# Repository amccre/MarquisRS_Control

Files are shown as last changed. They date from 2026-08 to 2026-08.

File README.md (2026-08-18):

# Marquis Recreational Series Hot Tub Control

ESPHome firmware, a custom display-decoder component, Home Assistant configuration, circuit documentation, and fabrication files for controlling and monitoring a Marquis Recreational Series hot tub with an ESP32.

> [!CAUTION]
> A spa combines lethal **120/240 V AC**, high-current equipment, water, and wet-location wiring. This is an experimental hobby project, not a listed or certified spa controller. Retain all factory safety controls and GFCI protection. Use appropriate isolation, fusing, grounding, strain relief, moisture protection, and enclosures. Disconnect and verify power before opening equipment. Installation should be completed or reviewed by a qualified electrician. You assume all risk.

<p align="center">
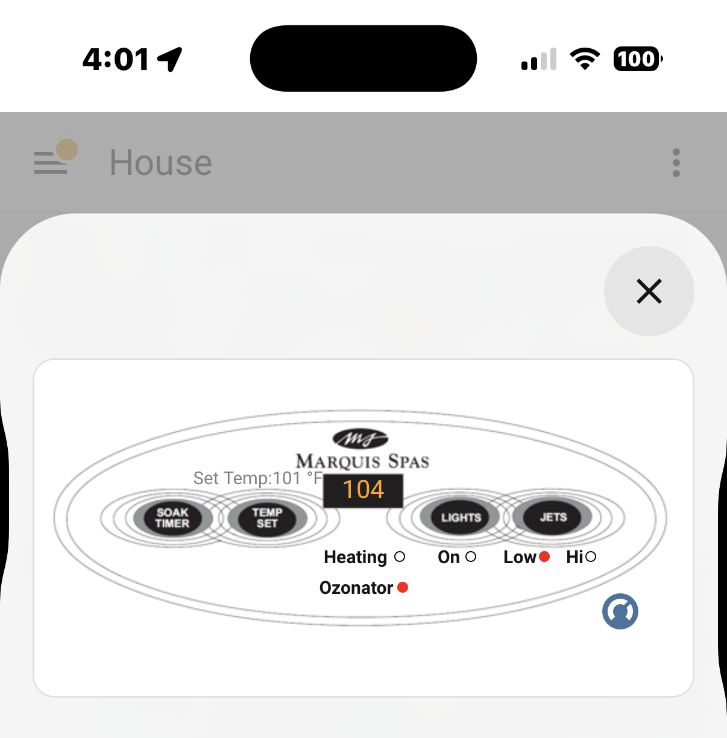
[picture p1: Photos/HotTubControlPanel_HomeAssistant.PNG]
Home Assistant hot tub control panel
  
</p>

## Overview

The project was developed for circa-2000-and-newer Marquis Recreational Series models such as the **Quest RS**, **Destiny RS**, and **Reward RS**. It preserves the original topside panel while adding network visibility and control:

- passively samples the panel clock and data lines;
- decodes the three-character, seven-segment LCD data and heater indicator;
- exposes **Soak Timer**, **Temp Set**, **Lights**, and **Jets** as Home Assistant buttons;
- monitors lights, ozonator, low-speed jets, and high-speed jets with split-core current transformers;
- creates a Home Assistant climate entity and target-temperature workflow; and
- provides example automations and a popup dashboard modeled after the original panel.

This implementation is hardware-specific. Marquis changed hardware over time, so verify connector pinout, logic levels, signal behavior, and button circuitry on your own equipment before connecting it.

## Repository Contents

```text
.
├── ESPHomeComponents/
│   └── marquis_rs_interface_component/
│       ├── hot-tub-control.yaml          # ESP32/ESPHome device configuration
│       ├── secrets.example.yaml          # Safe local-secret template
│       ├── README.md                     # Display protocol/component details
│       └── my_components/
│           └── marquis_rs_interface/     # Custom ESPHome component
├── HomeAssistantComponents/
│   ├── Automation-*.yaml                 # Four supporting automations
│   ├── script.hot_tub_*.txt              # Temperature-adjustment script
│   ├── DashboardExampleConfig.txt        # Example Lovelace view
│   ├── Helpers_Required.txt               # Required helper entities
│   ├── HACs_Components_Required.txt       # Third-party UI/integration list
│   └── files/
│       ├── configuration.yaml            # Climate/template configuration
│       └── www/                           # Dashboard image assets
├── Photos/                                # Build and finished-install images
├── ReverseEngineering/                    # Protocol captures and pinout research
├── CircuitDiagram.png                     # Browser-friendly circuit diagram
├── Circuit_Diagram.pdf                    # Printable circuit diagram
├── Circuit_Diagram.odg                    # Editable circuit source
├── Enclosure-Blank.stl                    # Blank enclosure model
├── HotTubControlEnclosure.stl             # Finished enclosure model
└── Buttons&CTs.txt                         # Original controls and CT notes
```

## Hardware

### Principal Components

| Quantity | Component | Purpose |
| ---: | --- | --- |
| 1 | ESP32 development board (`esp32dev`) | ESPHome controller and display decoder |
| 1 | ADS1115 at I²C address `0x48` | Four-channel CT input ADC |
| 2 | SCT-013-005, 5 A : 1 V | Lights and ozonator monitoring |
| 2 | SCT-013-010, 10 A : 1 V | Low- and high-speed jet monitoring |
| As required | Optocouplers/transistor stages | Isolated simulation of panel buttons |
| 1 | External USB power supply | Dedicated power for the ESP32/ESP8266 |
| As required | Fuse, connectors, enclosure | Safe permanent installation |

See the [PDF drawing](Circuit_Diagram.pdf), [editable ODG source](Circuit_Diagram.odg), and [original component notes](Buttons%26CTs.txt) before assembly.

<p align="center">
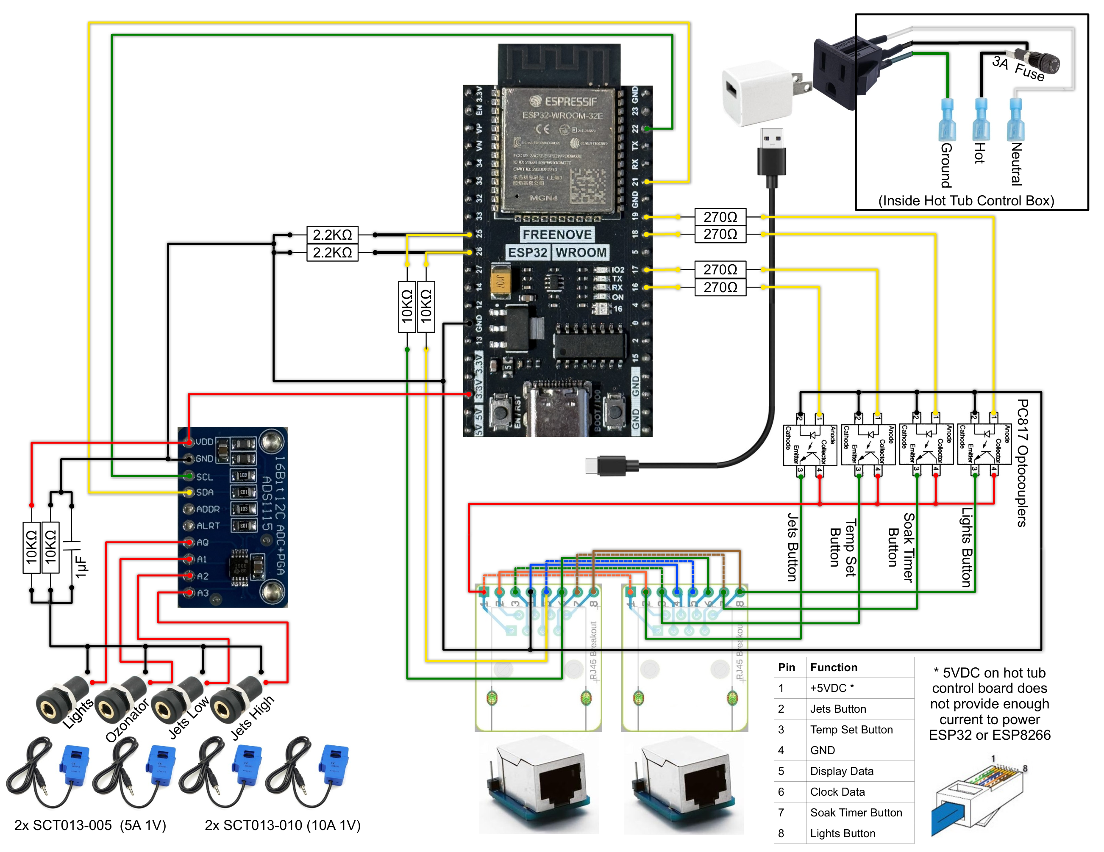
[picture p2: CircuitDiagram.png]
Marquis Recreational Series ESP32 interface circuit diagram
  
</p>

### Microcontroller Power

> [!IMPORTANT]
> The 5 V DC supplied by the hot tub control board does not provide enough current to power an ESP32 or ESP8266. The hot tub controller will reboot continuously if you try to use it to power the microcontroller. This made it necessary to use an external USB power supply.

Use a suitably rated, safety-certified USB supply and preserve the signal reference/isolation arrangement shown in the circuit diagram. Do not increase the load on the spa's 5 V rail in an attempt to eliminate the external supply. Keep the low-voltage USB supply and wiring protected from water, condensation, mains terminals, pumps, and heater conductors.

### ESP32 Pin Assignments

| Pin | Function |
| --- | --- |
| GPIO25 | Topside-display clock input |
| GPIO26 | Topside-display data input |
| GPIO19 | Lights button output |
| GPIO18 | Soak Timer button output |
| GPIO17 | Temp Set button output |
| GPIO16 | Jets button output |
| GPIO21 | ADS1115 SDA |
| GPIO22 | ADS1115 SCL |

Button outputs pulse for 150 ms. ESP32 pins must drive the documented interface circuitry; do **not** connect a GPIO directly to mains or an unverified panel circuit.

### Topside RJ45 Pinout

The reverse-engineering worksheet identifies the eight topside-connector conductors as follows. Confirm orientation and voltage on your own controller before relying on this table.

| RJ45 pin | Signal |
| ---: | --- |
| 1 | +5 V DC |
| 2 | Jets button |
| 3 | Temp Set button |
| 4 | Ground |
| 5 | Display data |
| 6 | Display clock |
| 7 | Soak Timer button |
| 8 | Light button |

### Current Monitoring

| ADS1115 channel | Load | Initial on-threshold | Calibration in supplied YAML |
| --- | --- | ---: | ---: |
| A0 | Lights | 0.75 A | 1 raw → 5 A |
| A1 | Ozonator | 0.05 A | 1 raw → 5 A |
| A2 | Jets low | 2 A | 1 raw → 10 A |
| A3 | Jets high | 2 A | 1 raw → 10 A |

These values describe one installation. Place each CT around **one conductor only**, compare readings with a trusted meter/known load, and tune both `calibrate_linear` and binary-sensor thresholds.

### Completed Installation

The finished interface is mounted in its printed enclosure near the spa equipment while preserving separation between the low-voltage electronics and high-voltage equipment wiring.

<table>
  <tr>
    <td align="center" width="50%">
      Completed Marquis hot tub controller installation, first view<br>
      <sub>Mounted controller and surrounding equipment</sub>
    </td>
    <td align="center" width="50%">
      Completed Marquis hot tub controller installation, second view<br>
      <sub>Installed enclosure and wiring, alternate view</sub>
    </td>
  </tr>
</table>

## ESPHome Installation

### 1. Copy the Project

Clone this repository on the host running ESPHome, then enter the component directory:

```bash
git clone https://github.com/amccre/MarquisRS_Control.git
cd MarquisRS_Control/ESPHomeComponents/marquis_rs_interface_component
```

### 2. Create Local Secrets

Copy `secrets.example.yaml` to `secrets.yaml` and replace every placeholder. The resulting file is ignored by Git.

```powershell
Copy-Item secrets.example.yaml secrets.yaml
```

Or on Linux/macOS:

```bash
cp secrets.example.yaml secrets.yaml
```

Required values are `wifi_ssid`, `wifi_password`, `api_encryption_key`, `ota_password`, and `fallback_ap_password`.

Generate a compatible API encryption key with `openssl rand -base64 32`, or let ESPHome generate one. Use unique random values for OTA and fallback access. Credentials formerly present in the local source were deliberately replaced with secret references and should be rotated if still in use.

### 3. Review and Flash

Before applying power, verify board type, GPIO assignments, ADS1115 address, logic levels, electrical isolation, CT channels, calibration, and thresholds.

```bash
esphome config hot-tub-control.yaml
esphome run hot-tub-control.yaml
```

Use USB for the initial flash. Once connected, later updates can use ESPHome OTA.

### 4. Add the Device to Home Assistant

In Home Assistant, open **Settings → Devices & services** and add the discovered ESPHome device. Supply the API encryption key from your local `secrets.yaml` when requested.

Expected entities include:

- `sensor.hot_tub_display` (the entity may initially include the ESPHome device prefix);
- `binary_sensor.hot_tub_control_heating`;
- lights, ozonator, jets-low, and jets-high binary sensors/current sensors; and
- four button entities for Soak Timer, Temp Set, Lights, and Jets.

Entity IDs in the supplied Home Assistant examples assume the names shown above. If Home Assistant generates different IDs, update the examples before enabling them.

## Home Assistant Configuration

The files in [`HomeAssistantComponents`](HomeAssistantComponents/) are examples to merge into an existing Home Assistant installation—not a drop-in replacement for your complete configuration.

### 1. Install Optional Custom Components

The supplied UI/configuration uses the following projects:

- [HACS](https://github.com/hacs/integration), to manage custom integrations;
- [Template Climate](https://github.com/jcwillox/hass-template-climate), required for `climate.hot_tub_thermostat`;
- [Bubble Card](https://github.com/Clooos/Bubble-Card), used for the popup panel;
- [card-mod](https://github.com/thomasloven/lovelace-card-mod), potentially needed for styling; and
- a `custom:text-action-element` card used by the example dashboard (install a compatible text-action element or replace those elements with built-in labels).

Restart Home Assistant after installing custom integrations/frontend resources.

### 2. Create Helpers

Create these helpers under **Settings → Devices & services → Helpers**:

| Entity ID | Type | Minimum | Maximum | Suggested icon |
| --- | --- | ---: | ---: | --- |
| `input_number.hot_tub_target_temperature` | Number | 80 | 104 | `mdi:target` |
| `input_number.hot_tub_set_temperature` | Number | 80 | 104 | `mdi:hot-tub` |
| `input_number.hot_tub_temperature` | Number | 0 | 120 | `mdi:hot-tub` |
| `input_boolean.hot_tub_ignore_sync` | Toggle | — | — | `mdi:pause` |

Use a step of `1` and °F as the unit for the number helpers. Template sensors are created in the next step.

### 3. Merge the Climate and Template Configuration

Merge [`HomeAssistantComponents/files/configuration.yaml`](HomeAssistantComponents/files/configuration.yaml) into your Home Assistant `configuration.yaml`. Do **not** overwrite an existing file wholesale. If you already have `climate:` or `template:` sections, merge entries while preserving valid YAML structure.

The configuration creates `climate.hot_tub_thermostat`, `sensor.hot_tub_temperature`, `sensor.hot_tub_set_temperature`, and `sensor.hot_tub_error_code`.

Run **Developer Tools → YAML → Check configuration**, then restart Home Assistant.

### 4. Add the Script and Automations

Import or recreate the supplied script first:

- [`script.hot_tub_read_adjust_to_target.txt`](HomeAssistantComponents/script.hot_tub_read_adjust_to_target.txt) reads the displayed setpoint and repeatedly presses Temp Set until the requested target is reached.

Then add the four automations:

1. [`Automation-Capture_Blinking_Set-Temp.yaml`](HomeAssistantComponents/Automation-Capture_Blinking_Set-Temp.yaml) captures the blinking setpoint display.
2. [`Automation-Record_LCD_temperature_when_stable.yaml`](HomeAssistantComponents/Automation-Record_LCD_temperature_when_stable.yaml) records stable water-temperature readings.
3. [`Automation-Sync_Set-Temp→Target.yaml`](HomeAssistantComponents/Automation-Sync_Set-Temp%E2%86%92Target.yaml) synchronizes a manually observed setpoint to the target helper.
4. [`Automation-Apply_New_Target_Temp.yaml`](HomeAssistantComponents/Automation-Apply_New_Target_Temp.yaml) invokes the adjustment script after the target changes.

Review every entity ID before enabling these automations. The adjustment script physically issues button presses and assumes the panel wraps through its setpoint range; test it while observing the real panel.

### 5. Install Dashboard Assets and Example

Copy the contents of [`HomeAssistantComponents/files/www`](HomeAssistantComponents/files/www/) to Home Assistant's `/config/www/`. Files there are exposed as `/local/...` URLs after a restart/browser refresh.

Use [`DashboardExampleConfig.txt`](HomeAssistantComponents/DashboardExampleConfig.txt) as a starting point for a raw Lovelace dashboard. It contains installation-specific floor-plan positioning and an `/api/image/serve/...` reference; replace that background with your own image URL or upload the desired panel image to `/config/www/` and use `/local/<filename>`.

## How Display Decoding Works

The custom [`marquis_rs_interface`](ESPHomeComponents/marquis_rs_interface_component/my_components/marquis_rs_interface/) component samples the panel data line on display-clock edges and reconstructs 21-bit frames, sent most-significant bit first.

<p align="center">
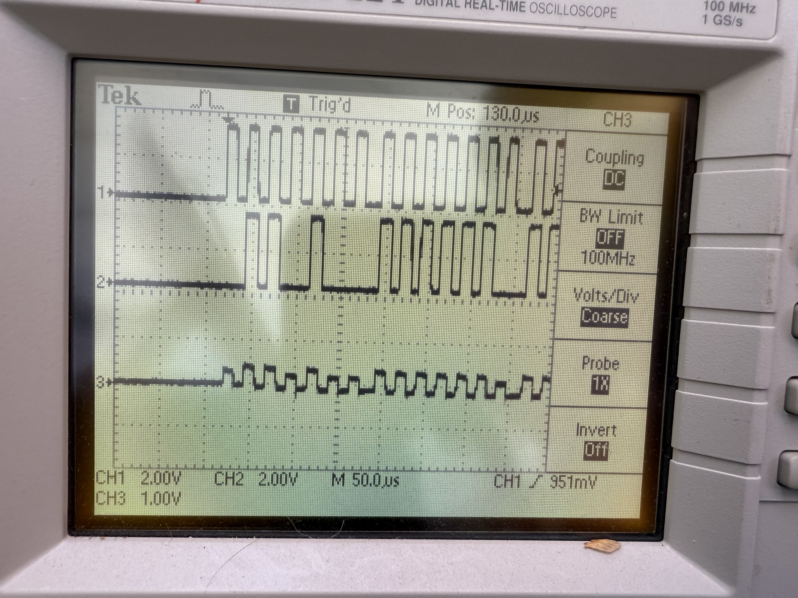
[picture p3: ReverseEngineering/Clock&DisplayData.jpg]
Oscilloscope capture of the Marquis topside display clock and data signals
  
</p>

### Display Data and Clock Timing

Measurements from the captured installation show:

- data starts **1 µs before** the clock pulse;
- data ends **1 µs after** the clock pulse;
- each data pulse is **12 µs** wide;
- gaps between pulses are **12 µs**;
- gaps between display segments are **19 µs**;
- gaps between complete sequences are approximately **17 ms**; and
- button-control pulses are **150 ms**.

The firmware interrupt is triggered by a rising clock edge and waits approximately **16 µs** before reading the data line. After **21 clocked bits**, the completed frame is queued for decoding. The implementation also treats a gap over **1,000 µs (1 ms)** as a frame boundary; the measured 17 ms inter-sequence gap comfortably exceeds that threshold. These values were measured on this installation and are not a manufacturer-guaranteed protocol specification, so remeasure if another controller revision behaves differently.

```text
Bit:      20 | 19 18 | 17 | 16 | 15 14 | 13 ........ 7 | 6 ......... 0
Meaning:   - | first |  - |heat|   -   | middle digit | final digit
```

- Bits 19–18 indicate a leading `1` or blank.
- Bit 16 is the heater indicator.
- Bits 13–7 and 6–0 hold seven-segment character patterns.
- Three consecutive identical frames are required to reject noise; stable state publication is rate-limited to 100 ms.
- A 16-frame ring buffer transfers captures from the interrupt handler to ESPHome's main loop.

### Seven-Segment Character Decoding

The final 14 frame bits represent two seven-segment characters. Each seven-bit value maps segments `A` through `G`, ordered from most-significant to least-significant bit:

```text
       A
      ---
   F |   | B
      -G-
   E |   | C
      ---
       D

Bit order: A B C D E F G
```

For example, `1111110` lights segments A–F and leaves G off, producing `0`; `0110000` lights B and C, producing `1`; and `1101101` produces `2`. The component contains a lookup table for digits `0`–`9`, a useful subset of letters shown by spa status/error codes, blank (`0000000`), and `?` for an unknown pattern. A leading `1` is encoded separately in frame bits 19–18, allowing the three-character display to represent values such as `102` as well as two-digit temperatures.

See the [component documentation](ESPHomeComponents/marquis_rs_interface_component/README.md) and [`ReverseEngineering`](ReverseEngineering/) folder for protocol details and captures.

An example [`ESPHomeLogs.png`](Photos/ESPHomeLogs.png) screenshot is included with the build photos as a reference for the decoded output seen during operation.

## Troubleshooting

### Display is blank, unstable, or shows `???`

- Verify connector pinout and signal voltage with appropriate test equipment.
- Confirm clock, data, and reference connections.
- Use high-impedance taps and appropriate level shifting/buffering.
- Keep low-voltage signal wiring away from motors, relays, and heater wiring.
- Enable debug logging while diagnosing frame capture.

### Current-based state is always on or off

- Inspect the underlying current sensor value.
- Confirm the CT surrounds one conductor, not both line and return.
- Verify ADS1115 channel assignments and CT type.
- Calibrate with a known load, then adjust state thresholds.

### A control button does not work

- Verify the isolation/driver circuit, polarity, and selected panel switch.
- Confirm a 150 ms closure is suitable for the physical panel.
- Never attach a bare GPIO to an unknown-voltage circuit.

### Climate target does not track correctly

- Confirm the display entity contains a numeric value during normal operation.
- Confirm all helper and ESPHome entity IDs match the example YAML.
- Ensure the four automations and adjustment script are enabled.
- Observe the panel while testing to validate blink timing and setpoint wraparound.

## Security

- `secrets.yaml`, ESPHome build state, IDE metadata, and Python caches are ignored.
- The checked-in ESPHome YAML references secrets rather than storing credentials.
- Rotate credentials that were ever embedded in another copy of this project.
- Repository visibility is not a substitute for secret management.

## License

This project is licensed under the [GNU General Public License v3.0 or later](LICENSE) (`GPL-3.0-or-later`). You may use, study, modify, and redistribute the project; if you distribute a modified version, the GPL requires the corresponding source and the same license freedoms to remain available. Marquis and other product names remain trademarks of their respective owners.

## Project Status and Disclaimer

This is a working DIY implementation, not a universal plug-and-play controller. There is no automated hardware-in-the-loop test suite. Calibrate and validate it against your installation, retain all factory protections, and keep manual control available.

This project is not affiliated with, endorsed by, or supported by Marquis Corp. Product names identify compatibility only. All files are supplied **as is**, without warranty. The user assumes all risk of code-compliance issues, warranty impact, property damage, equipment failure, electric shock, fire, injury, or death.

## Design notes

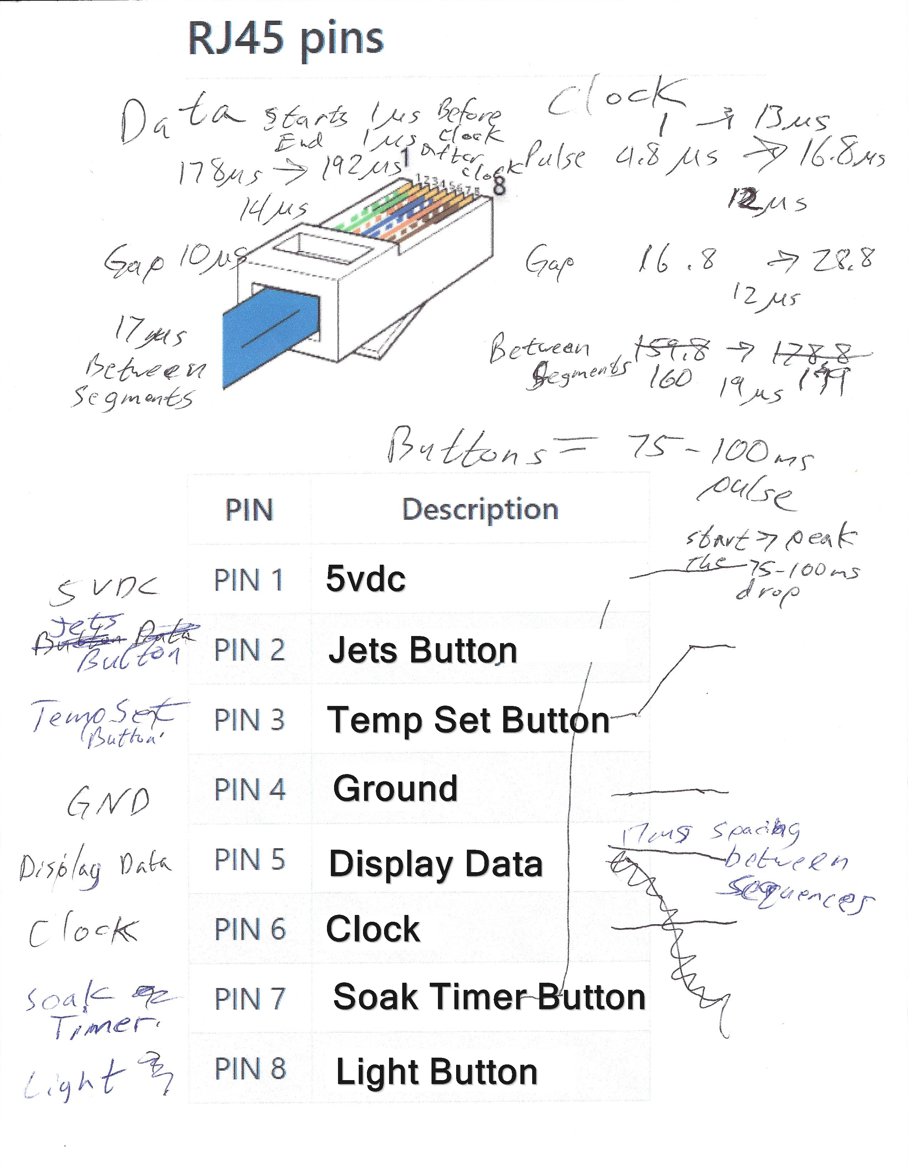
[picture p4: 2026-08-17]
ReverseEngineering/RJ45-Pinout.png

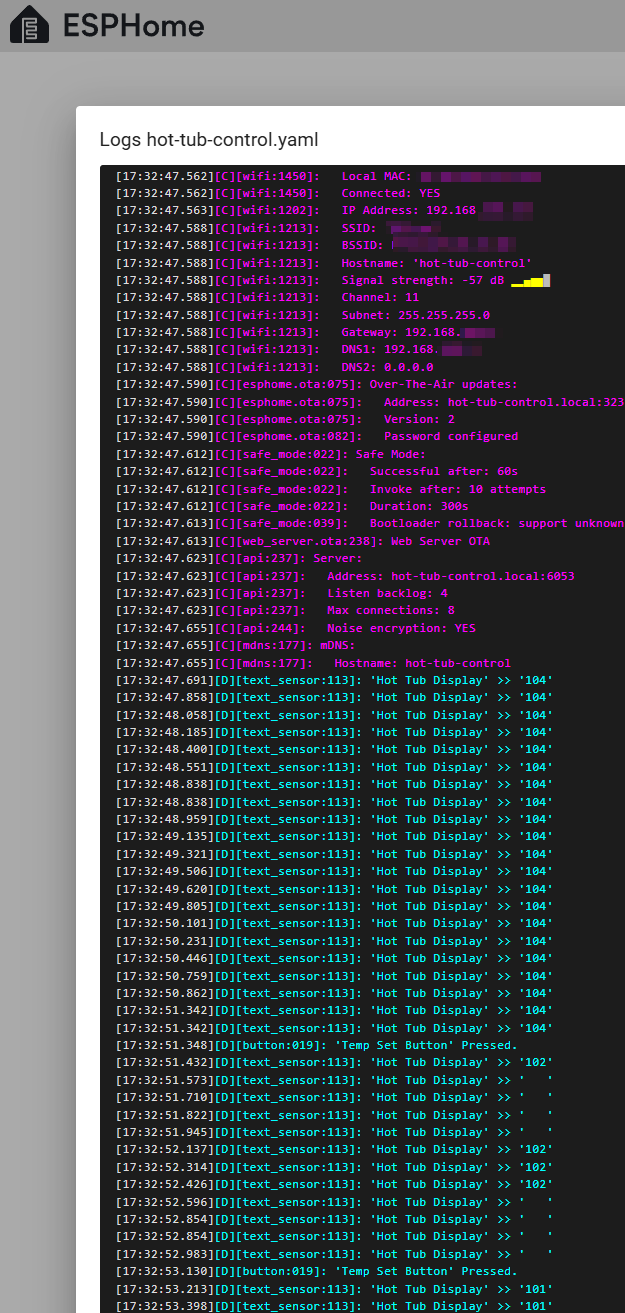
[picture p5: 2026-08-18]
Photos/ESPHomeLogs.png

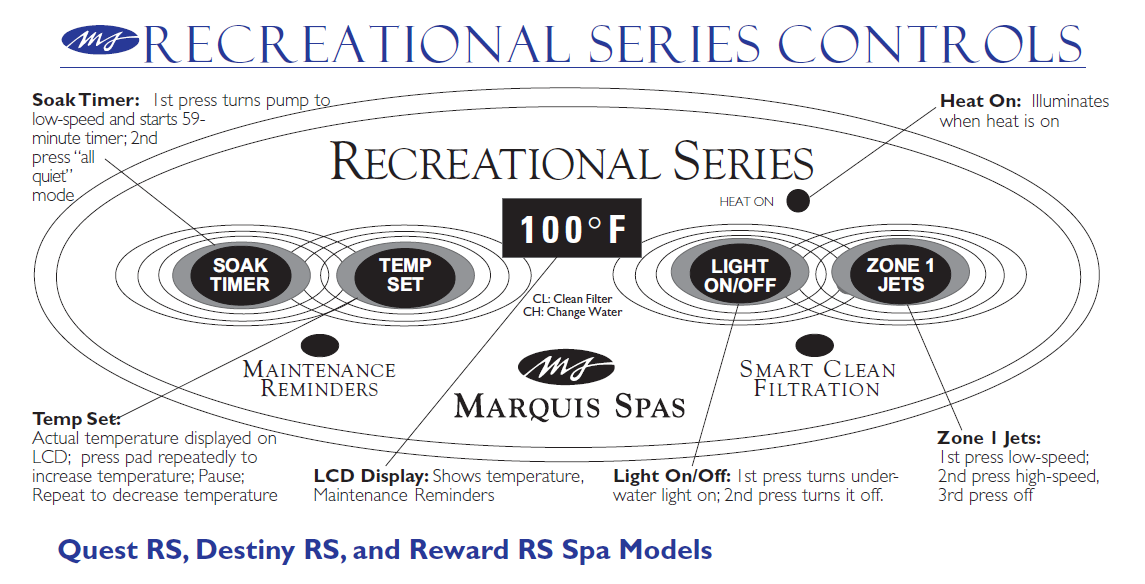
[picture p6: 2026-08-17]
Photos/Marquis_Recreational_Series_Controls.png

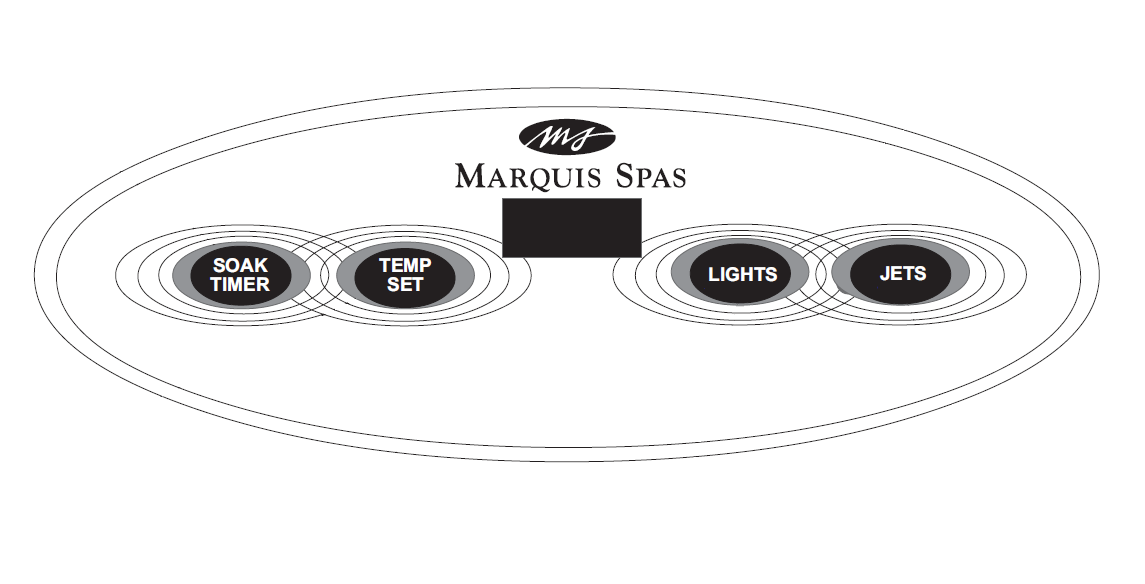
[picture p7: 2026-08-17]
Photos/Hot_Tub_Control_Panel.png

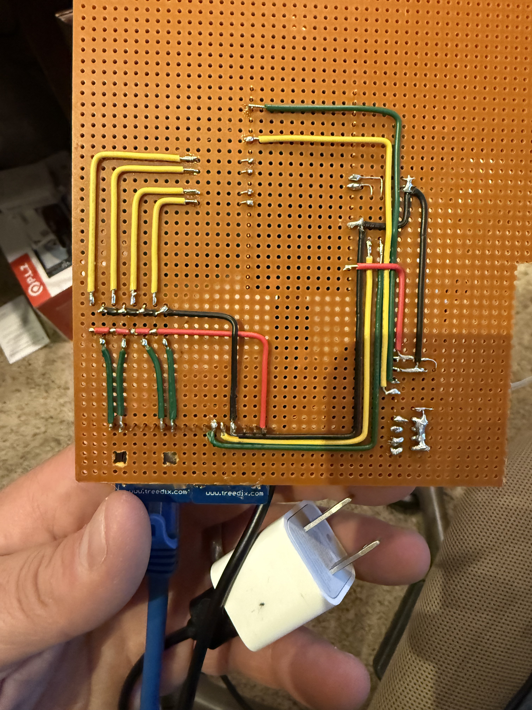
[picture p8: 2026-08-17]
Photos/CircuitBottom.jpg

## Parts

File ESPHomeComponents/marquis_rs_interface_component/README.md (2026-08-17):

# Marquis Recreational Series Hot Tub Controller

## Overview

This project provides a complete ESPHome-based control and monitoring system for Marquis Recreational Series hot tubs (Quest RS, Destiny RS, Reward RS, circa 2000+). It interfaces with the hot tub's topside control panel to read display information and heating status, while also providing button control and current monitoring capabilities for various hot tub functions.

### Key Features

- **Non-invasive LCD Display Reading**: Taps into the serial communication between the hot tub controller and LCD display
- **Real-time Status Monitoring**: Tracks heating status, temperature display, and component operation
- **Button Control**: Simulates physical button presses for lights, jets, temperature, and soak timer
- **Current Monitoring**: Uses CT clamps to detect operation of lights, ozonator, and jet pumps
- **Home Assistant Integration**: Full integration via ESPHome API for automation and monitoring

---

## Hardware Architecture

### Required Components

1. **ESP32 Development Board** (esp32dev)
2. **ADS1115 16-bit ADC** (I2C address 0x48)
3. **CT Clamp Current Sensors** (4x)
   - Lights monitoring  (SCT-013-005   5A:1V)
   - Ozonator monitoring  (SCT-013-005   5A:1V)
   - Jets low speed monitoring (SCT-013-010   10A:1V)
   - Jets high speed monitoring (SCT-013-010   10A:1V)
   - Heating (Not Needed, detected via LCD display logic)
4. **GPIO Output Drivers** for button simulation

### GPIO Pin Assignments

#### LCD Signal Tapping
- **GPIO25**: Clock signal from hot tub controller to LCD
- **GPIO26**: Data signal from hot tub controller to LCD

These pins passively read the serial communication without interfering with normal operation.

#### Button Control Outputs
- **GPIO19**: Lights button output
- **GPIO18**: Soak timer button output
- **GPIO17**: Temperature set button output
- **GPIO16**: Jets button output

These outputs simulate button presses with 150ms duration pulses.

#### I2C Bus (ADS1115 ADC)
- **GPIO21**: I2C SDA
- **GPIO22**: I2C SCL

#### ADS1115 ADC Channels
- **A0**: Lights current sensing
- **A1**: Ozonator current sensing
- **A2**: Jets low speed current sensing
- **A3**: Jets high speed current sensing

All channels configured with 6.144V gain for safety and wide dynamic range.

---

## Custom Component: marquis_rs_interface

### Purpose

The custom ESPHome component decodes the serial protocol between the hot tub's main controller and the topside LCD display. This protocol carries temperature readings, heating status, and error codes.

### Communication Protocol

#### Frame Structure
- **21-bit serial frames** transmitted on clock edges
- **MSB-first** bit ordering
- **Frame timing**: >1000μs gap indicates new frame start
- **Bit timing**: ~16μs data line stabilization delay after clock edge

#### Frame Bit Layout (21 bits)

```
Bit Position:   20 | 19 18 | 17 | 16 | 15  14 | 13 12 11 10 9 8 7 | 6 5 4 3 2 1 0
               ----+-------+----+----+--------+-------------------+---------------
Content:       null| First |null|Heat|  null  |  Middle 7-segment | Last 7-segment
                   | Digit |    |    |        |                   |
               ----|-------|----|----|--------|-------------------|---------------
               1bit| 2bits |1bit|1bit| 2bits  |    7 bits         |    7 bits
               ----|-------|----|----|--------|-------------------|---------------
                 a |  b c  |  d | e  | f   g  | a  b  c  d  e f g | a b c d e f g
               ----|-------|----|----|--------|-------------------|---------------
```

- **Bits 19-18**: First digit (hundreds place)
  - `00` = blank space (no hundreds digit shown)
  - `!= 00` = '1' displayed (for temperatures ≥100°F)
  
- **Bit 16**: Heating indicator
  - `1` = Heater ON
  - `0` = Heater OFF
  
- **Bits 13-7**: Middle digit (7-segment encoded)
  
- **Bits 6-0**: Last digit (7-segment encoded)

#### 7-Segment Encoding

Each digit uses standard 7-segment display encoding:

```
    A
   ---
F |   | B
   -G-
E |   | C
   ---
    D

Bit order: A-B-C-D-E-F-G (MSB to LSB)
```

Complete mappings:
- `0b1111110` = '0'
- `0b0110000` = '1'
- `0b1101101` = '2'
- `0b1111001` = '3'
- `0b0110011` = '4'
- `0b1011011` = '5'
- `0b1011111` = '6'
- `0b1110000` = '7'
- `0b1111111` = '8'
- `0b1111011` = '9'
- `0b1110111` = 'A'
- `0b0011111` = 'b'
- `0b1001110` = 'C'
- `0b0111101` = 'd'
- `0b1001111` = 'E'
- `0b1000111` = 'F'
- `0b1011110` = 'G'
- `0b0110111` = 'H'
- `0b0000110` = 'I'
- `0b0111100` = 'J'
- `0b0111011` = 'K'
- `0b0001110` = 'L'
- `0b0010101` = 'n'
- `0b0011101` = 'o'
- `0b1100111` = 'P'
- `0b1110011` = 'q'
- `0b0000101` = 'r'
- `0b0001111` = 't'
- `0b0111110` = 'U'
- `0b0111111` = 'Y'
- `0b0000000` = ' ' (space)
- `default` = '?' (unknown pattern)

### Component Architecture

#### Class Structure

```cpp
class MarquisRSInterface : public Component {
 public:
  void setup() override;      // Initialize GPIO and ISR
  void loop() override;       // Process decoded frames
  void isr_read_bit();        // ISR for clock edge detection

  // Configuration setters
  void set_clock_pin(InternalGPIOPin *pin);
  void set_data_pin(InternalGPIOPin *pin);
  void set_heating_sensor(binary_sensor::BinarySensor *sensor);
  void set_display_sensor(text_sensor::TextSensor *sensor);

 protected:
  // GPIO pins for LCD signal tapping
  InternalGPIOPin *clock_pin_;
  InternalGPIOPin *data_pin_;

  // ESPHome sensors to publish data
  binary_sensor::BinarySensor *heating_sensor_{nullptr};
  text_sensor::TextSensor *display_sensor_{nullptr};

  // Ring buffer for frames (thread-safe ISR to main loop communication)
  static const uint8_t FRAME_BUFFER_SIZE = 16;
  volatile uint32_t frame_buffer_[FRAME_BUFFER_SIZE];
  volatile uint8_t frame_write_index_{0};
  volatile uint8_t frame_read_index_{0};

  volatile uint32_t current_frame_{0};
  volatile uint8_t bit_index_{0};
  volatile uint32_t last_edge_time_us_{0};

  uint32_t last_publish_time_{0};
  uint32_t last_display_change_time_{0};
  uint32_t last_valid_frame_{0};
  uint8_t repeat_count_{0};

  std::string last_display_;
  uint8_t same_count_{0};

  char segment_to_char(uint8_t seg);
};
```

#### Interrupt Service Routine (ISR)

The `isr_read_bit()` function is called on every rising edge of the clock signal:

1. **Frame Detection**: Measures time gap since last edge
   - Gap >1000μs indicates new frame start
   - Resets bit counter and current frame buffer

2. **Data Sampling**: After 16μs stabilization delay
   - Reads data pin state (HIGH or LOW)
   - Shifts bit into appropriate position in 21-bit frame

3. **Frame Completion**: After 21 bits collected
   - Adds completed frame to decode queue
   - Resets for next frame

#### Main Loop Processing

The `loop()` function runs in the main ESPHome event loop:

1. **Frame Retrieval**: Processes frames from ISR queue (FIFO)

2. **Bit Extraction**: Extracts heating status and 7-segment data

3. **Character Decoding**: Converts 7-segment codes to ASCII characters

4. **Validation**: Uses repeat count for noise rejection
   - Requires 3 consecutive identical frames before publishing
   - Prevents spurious readings from electrical noise

5. **State Publishing**: Updates ESPHome sensors
   - `heating_sensor`: Binary state (ON/OFF)
   - `display_sensor`: 3-character text string

### Character Decoding

The `segment_to_char()` function maps 7-segment bit patterns to characters:

- **Digits 0-9**: Standard numeric display
- **Letters**: A, b, C, d, E, F, G, H, I, J, K, L, n, o, P, q, r, t, U, Y
- **Special**: Space (all segments off), '?' (unknown pattern)

This allows decoding of:
- Temperature readings (e.g., "102", " 98")
- Error codes (e.g., "FLo", "dr ", "SnS")
- Status messages

---

## ESPHome Configuration

### Component Declaration

```yaml
marquis_rs_interface:
  id: marquis_spa              # Component instance ID
  clock_pin: GPIO25            # LCD clock signal input
  data_pin: GPIO26             # LCD data signal input
  heating_sensor: heating      # Binary sensor for heater status
  display_sensor: display_text # Text sensor for display reading
```

### Binary Sensors

#### Heating Status Sensor
```yaml
binary_sensor:
  - platform: template
    name: "Hot Tub Heating"
    id: heating
    disabled_by_default: false
```
Updated by the custom component with real-time heating status.

#### Current-Based Detection Sensors

These sensors use current monitoring to detect component operation:

```yaml
  - platform: template
    name: Lights
    id: lights
    condition:
      sensor.in_range:
        id: lights_current
        above: 0.75           # Threshold: 0.75A

  - platform: template
    name: Ozonator
    condition:
      sensor.in_range:
        id: ozonator_current
        above: 0.05           # Threshold: 0.05A

  - platform: template
    name: Jets Low
    condition:
      sensor.in_range:
        id: jets_low_current
        above: 2              # Threshold: 2A

  - platform: template
    name: Jets High
    condition:
      sensor.in_range:
        id: jets_high_current
        above: 2              # Threshold: 2A
```

### Text Sensors

```yaml
text_sensor:
  - platform: template
    id: display_text
    name: "Hot Tub Display"
    disabled_by_default: false
    update_interval: 250ms    # Rapid updates for responsive display
```

### Current Monitoring Sensors

Each current sensor follows this pattern:

```yaml
sensor:
  # Raw ADC reading
  - platform: ads1115
    multiplexer: 'A0_GND'     # ADC channel
    gain: 6.144               # Voltage range
    name: "A0 RAW"
    accuracy_decimals: 2
    internal: True            # Hidden from UI
    id: a0_raw
    update_interval: 2000ms

  # CT clamp processing
  - platform: ct_clamp
    sensor: a0_raw            # Source sensor
    id: lights_current
    name: Lights Current
    sample_duration: 150ms    # RMS calculation window
    update_interval: 2000ms
    accuracy_decimals: 2
    filters:
      - calibrate_linear:
        - 0 -> 0              # Calibration points
        - 1 -> 5              # Raw -> Actual current (A, or 1 -> 10 for jets)
```

**Note**: Calibration values should be adjusted based on actual CT clamp specifications and load measurements. Jets sensors use 1 -> 10 calibration.

### Button Controls

```yaml
output:
  - platform: gpio
    id: lights_output
    pin: GPIO19
  - platform: gpio
    id: soak_timer_output
    pin: GPIO18
  - platform: gpio
    id: temp_set_output
    pin: GPIO17
  - platform: gpio
    id: jets_output
    pin: GPIO16

button:
  - platform: output
    name: "Soak Timer Button"
    output: soak_timer_output
    duration: 150ms
  - platform: output
    name: "Temp Set Button"
    output: temp_set_output
    duration: 150ms
  - platform: output
    name: "Lights Button"
    output: lights_output
    duration: 150ms
  - platform: output
    name: "Jets Button"
    output: jets_output
    duration: 150ms
```

---

## Installation and Setup

### 1. Hardware Installation

1. **Identify LCD connector** on hot tub control board
2. **Tap clock and data lines** with high-impedance connections
   - Use voltage dividers if levels exceed 3.3V
   - Ensure proper grounding between ESP32 and hot tub controller
3. **Install CT clamps** around power lines for each monitored component
4. **Connect button outputs** to hot tub control panel button pads
   - Use optocouplers or transistors for isolation
5. **Verify I2C connection** to ADS1115
6. **Ensure proper power supply** for ESP32 (stable 3.3V/5V)

### 2. Software Configuration

1. **Install ESPHome** on your system
2. **Copy custom component** files to `my_components/marquis_rs_interface/`
3. **Update WiFi credentials** in `hot-tub-control.yaml`:
   ```yaml
   wifi:
     ssid: !secret wifi_ssid
     password: !secret wifi_password
   ```
4. **Adjust API encryption key** for Home Assistant integration
5. **Calibrate current sensors** with known loads
6. **Flash ESP32** with ESPHome:
   ```bash
   esphome run hot-tub-control.yaml
   ```

### 3. Home Assistant Integration

1. The device will auto-discover via ESPHome API
2. Add to Home Assistant dashboard
3. Create automations based on:
   - Temperature readings
   - Heating status
   - Component operation states

---

## Troubleshooting

### Display Shows "???" or Garbage

- **Cause**: Signal levels incompatible or noise on data line
- **Solution**: 
  - Check voltage levels (should be 3.3V or 5V logic)
  - Add pull-up/pull-down resistors
  - Verify clock and data pin connections
  - Ensure common ground with hot tub controller

### Heating Status Not Updating

- **Cause**: Frame validation failing or bit 16 not being read correctly
- **Solution**:
  - Enable debug logging: `logger: level: DEBUG`
  - Check for frame repeat count issues
  - Verify clock edge detection in ISR

### Current Sensors Always Off/On

- **Cause**: Calibration issues or threshold problems
- **Solution**:
  - Monitor raw ADC values and actual current readings
  - Adjust `calibrate_linear` filter values
  - Modify threshold values in binary sensor conditions
  - Verify CT clamp orientation and placement

### Buttons Not Working

- **Cause**: Insufficient current/voltage to trigger button circuit
- **Solution**:
  - Use transistor or relay drivers for higher current
  - Adjust pulse duration (increase from 150ms if needed)
  - Verify connection to correct button pads

### WiFi Connection Issues

- **Cause**: Interference from hot tub equipment or signal strength
- **Solution**:
  - Use external antenna on ESP32
  - Add capacitors for power supply stability
  - Move ESP32 away from pump motors and heater

---

## Technical Implementation Details

### Why Interrupt Service Routine (ISR)?

The clock signal timing is critical and can occur at varying rates. Using an ISR ensures:
- **No missed bits**: Every clock edge is captured
- **Precise timing**: Microsecond-level accuracy
- **Minimal jitter**: Independent of main loop execution

### Frame Validation Strategy

The component uses several techniques to ensure accurate readings:

1. **Gap Detection**: >1000μs gap reliably indicates frame boundaries
2. **Repeat Counting**: Requires 3 identical consecutive frames
3. **Bit Length Validation**: Expects exactly 21 bits per frame
4. **Checksum Alternative**: Since no checksum exists in protocol, repetition provides validation

### Performance Considerations

- **ISR Execution Time**: Minimized to <50μs per bit
- **Frame Queue**: Uses ring buffer for thread-safe ISR-to-main-loop communication
- **Rate Limiting**: Updates published at most every 100ms to prevent overwhelming Home Assistant
- **Enhanced Flashing Detection**: Tracks display changes within 2-second windows
- **Memory Usage**: Minimal state tracking (few integers and booleans)
- **CPU Load**: Negligible impact on ESP32 with interrupt-driven design

### Future Enhancement Possibilities

1. **Write Capability**: Inject commands to control hot tub directly
2. **Error Code Database**: Decode and explain error messages
3. **Historical Data**: Log temperature trends and usage patterns
4. **Advanced Automation**: Predictive heating based on usage
5. **Multi-Controller Support**: Handle different Marquis series protocols

---

## Code File Structure

```
.
├── hot-tub-control.yaml                          # Main ESPHome configuration
└── my_components/
    └── marquis_rs_interface/
        ├── __init__.py                           # Python integration layer
        ├── component.yaml                        # Component metadata
        ├── marquis_rs_interface.h                # C++ header file
        └── marquis_rs_interface.cpp              # C++ implementation
```

### File Descriptions

- **`hot-tub-control.yaml`**: ESPHome configuration defining all sensors, buttons, and component instances
- **`__init__.py`**: Python code for ESPHome build system integration, validates configuration schema
- **`component.yaml`**: Metadata describing the component for ESPHome ecosystem
- **`marquis_rs_interface.h`**: C++ class declaration and public interface
- **`marquis_rs_interface.cpp`**: Core logic for frame decoding, ISR handling, and sensor publishing

---

## Safety and Warranty Considerations

⚠️ **Important Safety Information**:

1. **Electrical Hazard**: Hot tubs operate at 240V AC. All modifications should be performed by qualified personnel.
2. **Warranty Impact**: Modifying the hot tub control system may void manufacturer warranty.
3. **Isolation**: Use proper electrical isolation (optocouplers) between ESP32 and hot tub circuits.
4. **Water Protection**: Ensure ESP32 and electronics are protected from water and moisture.
5. **GFCI Protection**: Verify all electrical work maintains proper ground fault protection.

This project is provided as-is for educational and hobbyist purposes. The authors assume no liability for damages or injuries resulting from implementation.

---

## License

This project is open source. Please check individual file headers for specific licensing information.

## Credits

Developed for Marquis Recreational Series hot tubs (circa 2000+). Compatible models include Quest RS, Destiny RS, and Reward RS.

## Contributing

Contributions are welcome! Areas for improvement:
- Additional error code mappings
- Support for other Marquis series
- Enhanced filtering algorithms
- Calibration tools

---

## Appendix: Protocol Analysis

### Sample Frame Decoding

**Raw Frame**: `0b111001101111100110000`

Breaking down the 21 bits:
```
Bits 20-19: 11 (First digit = '1')
Bit 16:     1  (Heating = ON)
Bits 18-17, 15-7: 0011101 (Middle = '0')
Bits 6-0:   0110000 (Last = '1')
```

**Result**: Display shows "101", Heater is ON

### Common Display Values

| Display | Meaning |
|---|---|
| "102" | Temperature 102°F |
| " 98" | Temperature 98°F (no hundreds digit) |
| "FLo" | Flow error (check circulation pump) |
| "dr " | Drain mode |
| "SnS" | Sensor error |
| "---" | Reading not available |

---

**Last Updated**: December 1, 2025

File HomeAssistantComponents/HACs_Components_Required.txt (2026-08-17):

HACS - To allow installation of other custom integrations - https://github.com/hacs/integration
Template Climate - For creations of Climate entity in HA -  https://github.com/jcwillox/hass-template-climate
Bubble-Card - To allow hot tub control panel to popup - https://github.com/Clooos/Bubble-Card
Card-Mod - Might be needed for customizing things - https://github.com/thomasloven/lovelace-card-mod

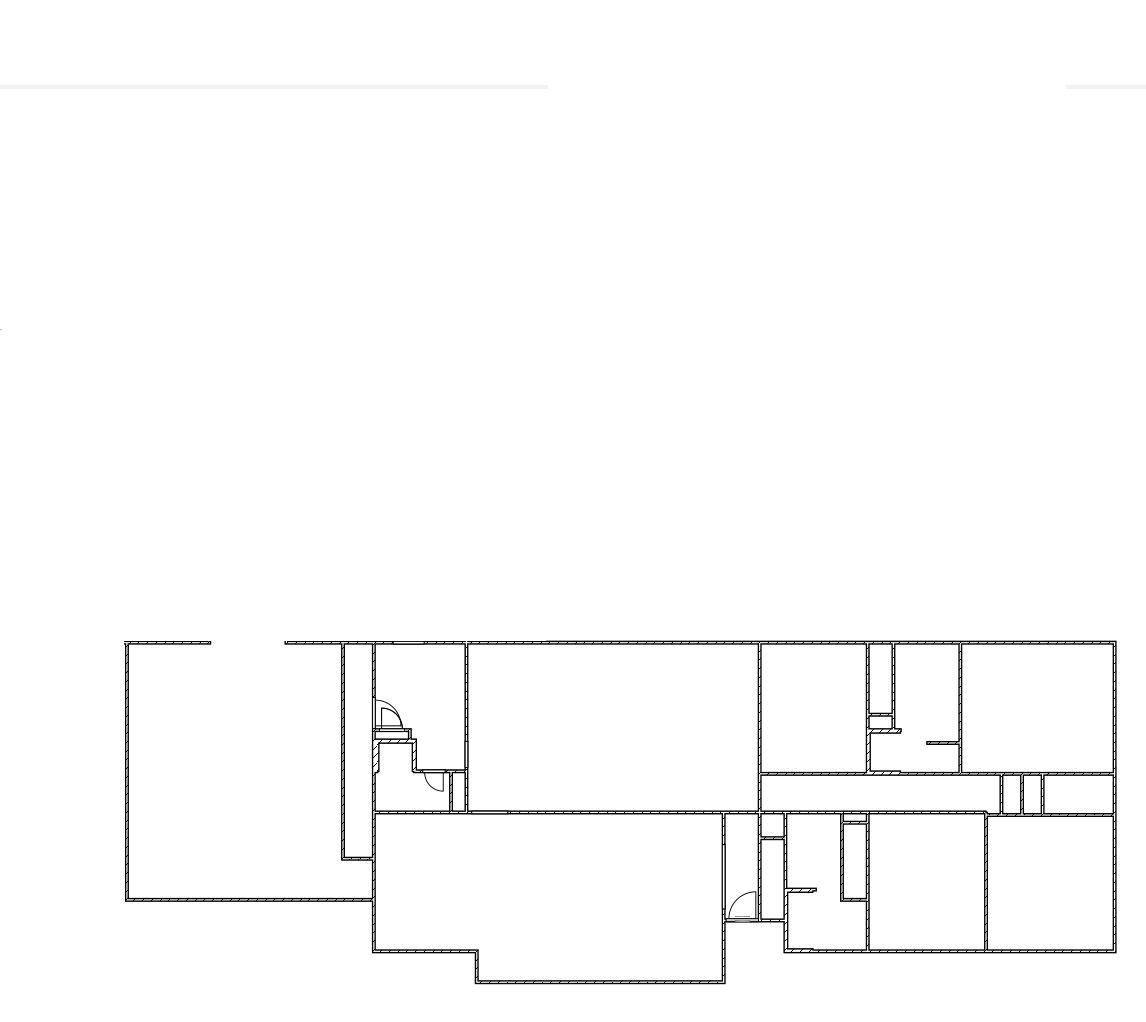
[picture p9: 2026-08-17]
HomeAssistantComponents/files/www/FloorPlanOnly.png

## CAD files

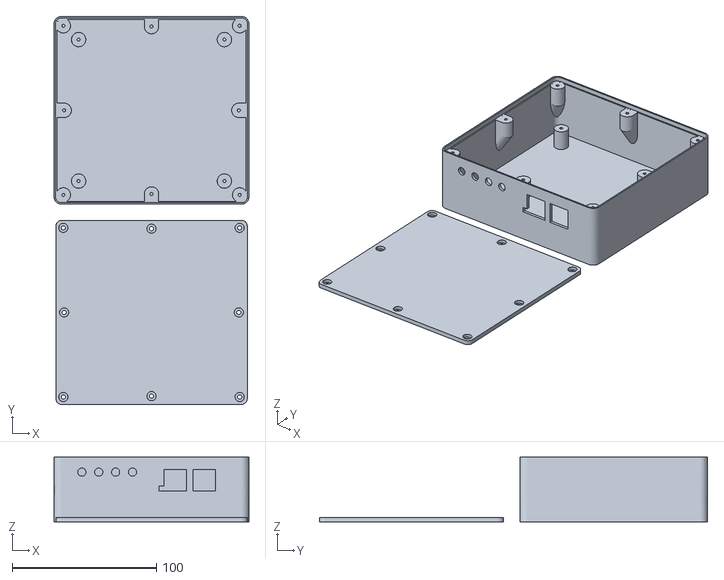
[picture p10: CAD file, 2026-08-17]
HotTubControlEnclosure.stl
135.0 x 268.8 x 45.0

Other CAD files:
Enclosure-Blank.stl

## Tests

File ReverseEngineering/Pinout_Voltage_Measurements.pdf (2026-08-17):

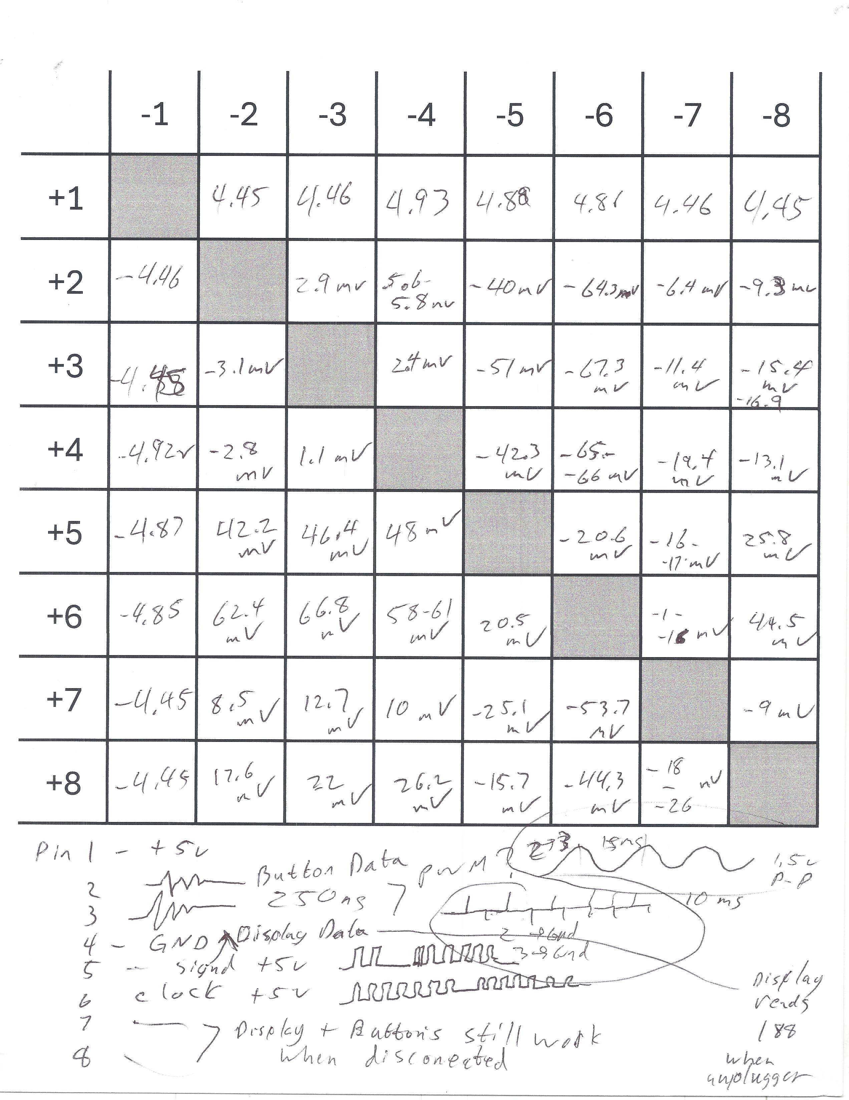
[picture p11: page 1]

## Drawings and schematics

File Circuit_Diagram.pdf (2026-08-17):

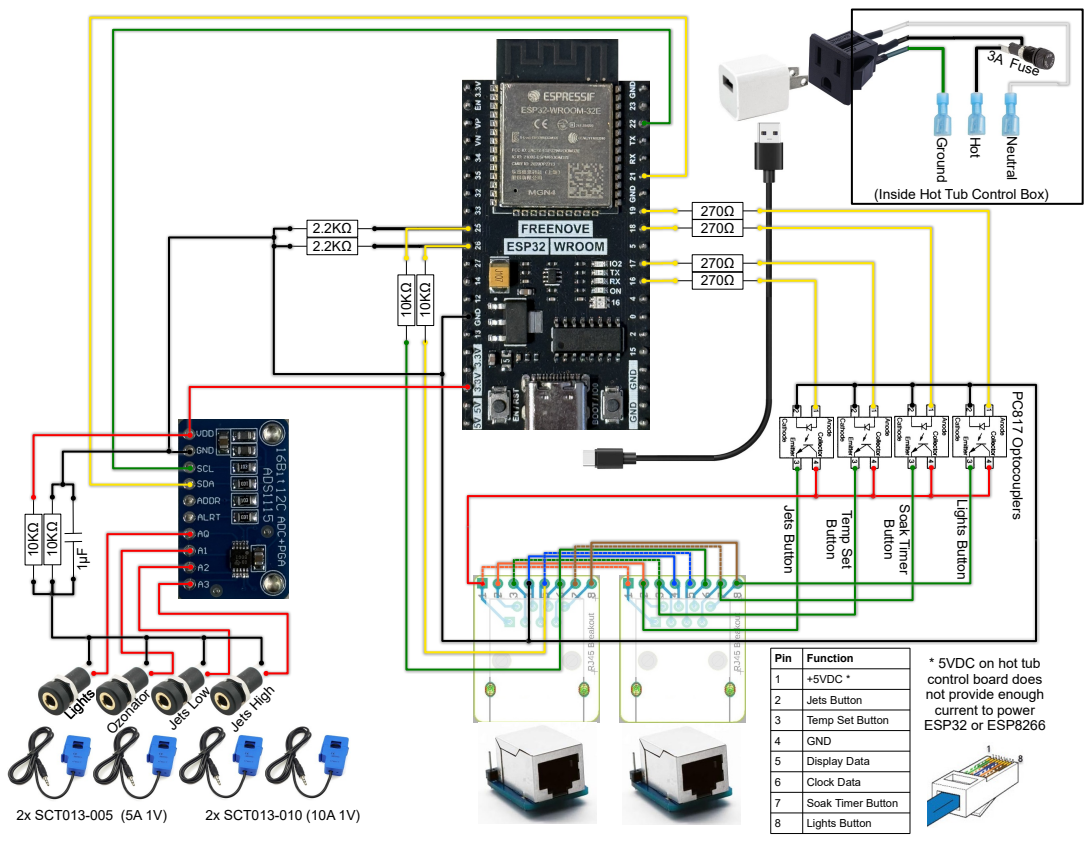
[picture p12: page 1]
3A Fuse; Ground; N eutral; O pto; c ouplers; 2x SCT013-005 (5A 1V); 2x SCT013-010 (10A 1V); Lights; Jets Button; Ozonator; Jets Low; Jets High; Button; S o ak Tim; Lights Button

(Inside Hot Tub Control Box)

Pin | Function
1 | +5VDC *
2 | Jets Button
3 | Temp Set Button
4 | GND
5 | Display Data
6 | Clock Data
7 | Soak Timer Button
8 | Lights Button

* 5VDC on hot tub
control board does
not provide enough
current to power
ESP32 or ESP8266

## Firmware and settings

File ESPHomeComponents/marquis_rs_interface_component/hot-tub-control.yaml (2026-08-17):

esphome:
  name: hot-tub-control
  friendly_name: hot-tub-control

external_components:
  - source: my_components
  
esp32:
  board: esp32dev
  framework:
    type: arduino



# Enable logging
# logger:
#  level: DEBUG
logger:
  level: DEBUG
  logs:
    ads1115.sensor: WARN
    ct_clamp: WARN
    sensor: WARN
    

# Enable Home Assistant API
api:
  encryption:
    # Keep deployment credentials in the local, ignored secrets.yaml file.
    key: !secret api_encryption_key

ota:
  - platform: esphome
    password: !secret ota_password

wifi:
  ssid: !secret wifi_ssid
  password: !secret wifi_password

  # Enable fallback hotspot (captive portal) in case wifi connection fails
  ap:
    ssid: "Hot-Tub-Control Fallback Hotspot"
    password: !secret fallback_ap_password

captive_portal:
    
binary_sensor:
  - platform: template
    name: "Hot Tub Heating"
    id: heating
    disabled_by_default: false

  - platform: template
    name: Lights
    id: lights
    condition:
      sensor.in_range:
        id: lights_current
        above: 0.75

  - platform: template
    name: Ozonator
    condition:
      sensor.in_range:
        id: ozonator_current
        above: 0.05

  - platform: template
    name: Jets Low
    condition:
      sensor.in_range:
        id: jets_low_current
        above: 2

  - platform: template
    name: Jets High
    condition:
      sensor.in_range:
        id: jets_high_current
        above: 2
        
text_sensor:
  - platform: template
    id: display_text
    name: "Hot Tub Display"
    disabled_by_default: false
    update_interval: 250ms


marquis_rs_interface:
  id: marquis_spa
  clock_pin: GPIO25
  data_pin: GPIO26
  heating_sensor: heating
  display_sensor: display_text

output:
  - platform: gpio
    id: lights_output
    pin: GPIO19
  - platform: gpio
    id: soak_timer_output
    pin: GPIO18
  - platform: gpio
    id: temp_set_output
    pin: GPIO17
  - platform: gpio
    id: jets_output
    pin: GPIO16

button:
  - platform: output
    name: "Soak Timer Button"
    output: soak_timer_output
    duration: 150ms
     
  - platform: output
    name: "Temp Set Button"
    output: temp_set_output
    duration: 150ms

  - platform: output
    name: "Lights Button"
    output: lights_output
    duration: 150ms

  - platform: output
    name: "Jets Button"
    output: jets_output
    duration: 150ms
 
###########################################################################

i2c:
  - id: bus_a
    sda: GPIO21
    scl: GPIO22
    scan: true
    #frequency: 800kHz
###########################################################################
  
ads1115:
  - address: 0x48
    i2c_id: bus_a
 #   continuous_mode: on
    continuous_mode: off
###########################################################################



sensor:

#--------------------------------------------------------------------------

# Lights  
  - platform: ads1115
    multiplexer: 'A0_GND'
    gain: 6.144
    name: "A0 RAW"
    accuracy_decimals: 2
    internal: True
    id: a0_raw
    update_interval: 2000ms


  - platform: ct_clamp
    sensor: a0_raw
    id: lights_current
    name: Lights Current
    sample_duration: 150ms
    update_interval: 2000ms
    accuracy_decimals: 2
    filters:
      - calibrate_linear:
        - 0 -> 0
        - 1 -> 5

#--------------------------------------------------------------------------

# Ozonator
  - platform: ads1115
    multiplexer: 'A1_GND'
    gain: 6.144
    name: "A1 RAW"
    accuracy_decimals: 2
    internal: True
    id: a1_raw
    update_interval: 2000ms


  - platform: ct_clamp
    sensor: a1_raw
    id: ozonator_current
    name: Ozonator Current
    sample_duration: 150ms
    update_interval: 2000ms
    accuracy_decimals: 2
    filters:
      - calibrate_linear:
        - 0 -> 0
        - 1 -> 5

#--------------------------------------------------------------------------

# Jets Low
  - platform: ads1115
    multiplexer: 'A2_GND'
    gain: 6.144
    name: "A2 RAW"
    accuracy_decimals: 2
    internal: True
    id: a2_raw
    update_interval: 2000ms


  - platform: ct_clamp
    sensor: a2_raw
    id: jets_low_current
    name: Jets Low Current
    sample_duration: 150ms
    update_interval: 2000ms
    accuracy_decimals: 2
    filters:
      - calibrate_linear:
        - 0 -> 0
        - 1 -> 10

#--------------------------------------------------------------------------

# Jets High
  - platform: ads1115
    multiplexer: 'A3_GND'
    gain: 6.144
    name: "A3 RAW"
    accuracy_decimals: 2
    internal: True
    id: a3_raw
    update_interval: 2000ms


  - platform: ct_clamp
    sensor: a3_raw
    id: jets_high_current
    name: Jets High Current
    sample_duration: 150ms
    update_interval: 2000ms
    accuracy_decimals: 2
    filters:
      - calibrate_linear:
        - 0 -> 0
        - 1 -> 10

#--------------------------------------------------------------------------

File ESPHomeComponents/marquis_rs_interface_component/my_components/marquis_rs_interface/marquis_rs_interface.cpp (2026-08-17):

#include "marquis_rs_interface.h"
#include "esphome/core/log.h"
#include <Arduino.h>

namespace esphome {
namespace marquis_rs_interface {

static const char *const TAG = "marquis_rs_interface";

// Map 7-segment MSB-to-LSB encoded bits to characters
char MarquisRSInterface::segment_to_char(uint8_t seg) {
  switch (seg) {
    case 0b1111110: return '0';
    case 0b0110000: return '1';
    case 0b1101101: return '2';
    case 0b1111001: return '3';
    case 0b0110011: return '4';
    case 0b1011011: return '5';
    case 0b1011111: return '6';
    case 0b1110000: return '7';
    case 0b1111111: return '8';
    case 0b1111011: return '9';
    case 0b1110111: return 'A';
    case 0b0011111: return 'b';
    case 0b1001110: return 'C';
    case 0b0111101: return 'd';
    case 0b1001111: return 'E';
    case 0b1000111: return 'F';
    case 0b1011110: return 'G';
    case 0b0110111: return 'H';
    case 0b0000110: return 'I';
    case 0b0111100: return 'J';
    case 0b0111011: return 'K';
    case 0b0001110: return 'L';
    case 0b0010101: return 'n';
    case 0b0011101: return 'o';
    case 0b1100111: return 'P';
    case 0b1110011: return 'q';
    case 0b0000101: return 'r';
    case 0b0001111: return 't';
    case 0b0111110: return 'U';
    case 0b0111111: return 'Y';
    case 0b0000000: return ' ';
    default:        return '?';
  }
}

void IRAM_ATTR gpio_isr_handler(void *arg) {
  static_cast<MarquisRSInterface *>(arg)->isr_read_bit();
}

void MarquisRSInterface::setup() {
  this->clock_pin_->setup();
  this->data_pin_->setup();

  gpio_num_t clock_pin_num = static_cast<gpio_num_t>(this->clock_pin_->get_pin());

  gpio_install_isr_service(0);
  gpio_set_intr_type(clock_pin_num, GPIO_INTR_POSEDGE);
  gpio_isr_handler_add(clock_pin_num, gpio_isr_handler, this);
}

void MarquisRSInterface::loop() {
  // Process only one frame per loop iteration to prevent blocking
  if (frame_read_index_ != frame_write_index_) {
    uint32_t frame = frame_buffer_[frame_read_index_];
    frame_read_index_ = (frame_read_index_ + 1) % FRAME_BUFFER_SIZE;

    char bits[22];
    for (int i = 0; i < 21; i++) {
      bits[i] = (frame & (1UL << (20 - i))) ? '1' : '0';
    }
    bits[21] = '\0';
    //ESP_LOGD(TAG, "Decoded Frame: %s (hex: 0x%05X)", bits, frame);

    bool heating = (frame >> 16) & 0x01;

    uint8_t first_seg = ((frame >> 18) & 0x03);
    uint8_t middle_seg = (frame >> 7) & 0x7F;
    uint8_t last_seg = frame & 0x7F;

    std::string display;
    // First digit: only shown if either bit 2 or 3 are set
    if (first_seg != 0) {
      display += '1';
    } else {
      display += ' ';
    }

    // Middle digit
    display += segment_to_char(middle_seg);

    // Last digit
    display += segment_to_char(last_seg);

    uint32_t now = millis();

    // Enhanced flashing detection: track display changes within 2-second windows
    bool display_changed = (display != last_display_);
    if (display_changed) {
      last_display_change_time_ = now;
      last_display_ = display;
      same_count_ = 1;
    } else {
      same_count_++;
    }

    // Rate limiting: publish at most every 100ms to prevent overwhelming Home Assistant
    bool should_publish = false;
    if (frame == last_valid_frame_) {
      if (++repeat_count_ >= 3) {
        should_publish = (now - last_publish_time_ >= 100);
        repeat_count_ = 0;
      }
    } else {
      repeat_count_ = 1;  // Start counting this new frame
      last_valid_frame_ = frame;
    }

    if (should_publish) {
      if (heating_sensor_ != nullptr)
        heating_sensor_->publish_state(heating);
      if (display_sensor_ != nullptr)
        display_sensor_->publish_state(display);
      last_publish_time_ = now;
    }
  }
}

void IRAM_ATTR MarquisRSInterface::isr_read_bit() {
  const uint32_t now = micros();
  const uint32_t gap = now - last_edge_time_us_;
  last_edge_time_us_ = now;

  bool new_frame = false;
  if (gap > 1000 || bit_index_ >= 21) {
    bit_index_ = 0;
    current_frame_ = 0;
    new_frame = true;
  }

  // Use digitalRead for Arduino framework compatibility (delay already removed for timing)
  gpio_num_t data_pin_num = static_cast<gpio_num_t>(this->data_pin_->get_pin());
  bool data_high = digitalRead(data_pin_num);

  if (data_high) {
    current_frame_ |= (1UL << (20 - bit_index_));
  }

  bit_index_++;

  if (bit_index_ >= 21) {
    bit_index_ = 0;
    // Write to ring buffer (thread-safe: ISR writes, main loop reads)
    uint8_t next_write = (frame_write_index_ + 1) % FRAME_BUFFER_SIZE;
    if (next_write != frame_read_index_) {  // Prevent overflow
      frame_buffer_[frame_write_index_] = current_frame_;
      frame_write_index_ = next_write;
    }
  }
}

void MarquisRSInterface::set_clock_pin(InternalGPIOPin *pin) {
  clock_pin_ = pin;
}

void MarquisRSInterface::set_data_pin(InternalGPIOPin *pin) {
  data_pin_ = pin;
}

void MarquisRSInterface::set_heating_sensor(binary_sensor::BinarySensor *sensor) {
  heating_sensor_ = sensor;
}

void MarquisRSInterface::set_display_sensor(text_sensor::TextSensor *sensor) {
  display_sensor_ = sensor;
}

}  // namespace marquis_rs_interface
}  // namespace esphome

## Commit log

2026-08-17 Import Marquis RS hot tub control project
    [Enclosure-Blank.stl, HotTubControlEnclosure.stl, Pinout_Voltage_Measurements_BlankSheet.xlsx]
2026-08-17 Rebuild project from complete Marquis RS source
    [DashboardExampleConfig.txt]
